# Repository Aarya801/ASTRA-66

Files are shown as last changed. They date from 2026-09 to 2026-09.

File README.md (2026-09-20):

<div align="center">

# ASTRA-66

### Parametric rocket airframe · engineering analysis · flight simulation · data-only avionics framework

**A 66 mm-class student rocket airframe designed, analysed, simulated and software-validated end to end — reproducible with one command.**









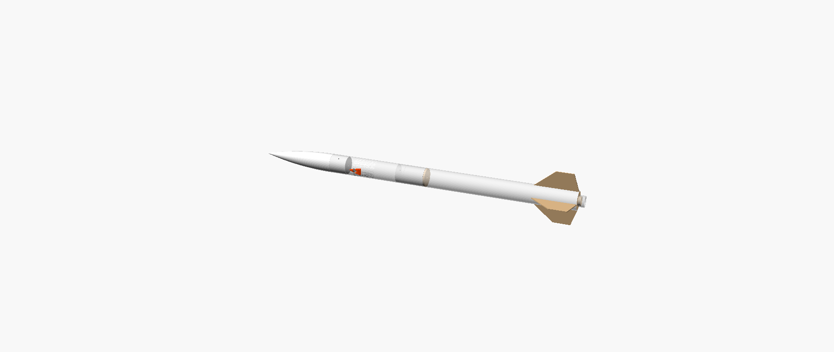
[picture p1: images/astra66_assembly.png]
ASTRA-66 assembly rendered from the OpenSCAD model


</div>

> [!IMPORTANT]
> **ASTRA-66 is an educational engineering project and is NOT FLIGHT CERTIFIED.**
> Nothing has been built or flown. No avionics hardware has been selected, bought, weighed or tested, and every
> avionics dataset is synthetic. Propulsion is an external, commercially certified component that is never designed,
> modified or specified here, and its data are placeholders. Any launch would require review and sign-off by a
> qualified rocketry mentor or institution and the range safety officer.

---

## What is ASTRA-66?

ASTRA-66 is a 66 mm-class, 1144 mm modular rocket airframe built as a **complete engineering pipeline** rather than a
drawing exercise:

- one parameter file is the single source of truth;
- the CAD is generated from it and then **measured** — volumes, interferences, assembly feasibility, printability;
- the analysis consumes those measured meshes; the simulation consumes the analysis;
- a data-only avionics software framework is exercised against synthetic sensor data through the same code path a
  flight computer would run;
- and a single command re-validates all of it, in CI, on two Python versions.

The engineering problem is **consistency and honesty**: keeping CAD, analysis, simulation and software in agreement,
and labelling every number as verified, calculated, assumed, placeholder or unknown.

| | |
|---|---|
| **Vehicle class** | 66 mm diameter · 1144 mm length · 4 fins · single parachute |
| **Modules** | Nose · payload bay · avionics bay · booster (all separable) |
| **Avionics** | Sense, log, transmit only — no actuation of any kind |
| **Propulsion** | External, commercially certified component (placeholder data only) |
| **Codebase** | 67 Python files (~10 200 lines) · 30 OpenSCAD files (~950 lines) · standard library only |
| **Artefacts** | 282 tracked files: CAD exports, drawings, plots, datasets, 37 documents |

📖 **Start here:** [Project overview](documentation/PROJECT_OVERVIEW.md) ·
[Engineering method](documentation/ENGINEERING_METHOD.md) · [What is validated](documentation/VALIDATION.md) ·
[Release readiness](documentation/RELEASE_READINESS.md)

---

## System architecture

<div align="center">
ASTRA-66 system architecture: CAD, analysis, simulation, avionics software, replay and validation, with the boundary to physical hardware validation
</div>

Everything above the red line is performed, reproducible and runs in CI. Everything below it — hardware integration
and experimental data — **has not been done**.

<details>
<summary><b>Data flow in text form</b></summary>

```
analysis/analysis.py ──► build.py ──► cad/astra66_params.scad ──► cad/build_cad.py (OpenSCAD, optional)
        │                    │                                          │
        │                    └► engineering package, BOM, drawings      └► CAD validation + CAD-derived masses
        ▼
simulation/flight_simulation.py ──► stability, sensitivity, verification, plots, reports
        ▲                                   │
simulation/motor_config.json (EXTERNAL,     └► simulation/avionics_replay.py ──► avionics/firmware
currently PLACEHOLDER)                                                           (the same pipeline a flight
                                                                                  computer would run)
```
</details>

---

## CAD

Parametric OpenSCAD model: **25 designed parts + master assembly**, driven by the generated parameter file.
Commercial items (motor envelope, retainer, rail buttons, eyebolt, electronics) appear only as **envelopes**.

<div align="center">

| Assembly | Exploded | Half-section |
|:---:|:---:|:---:|
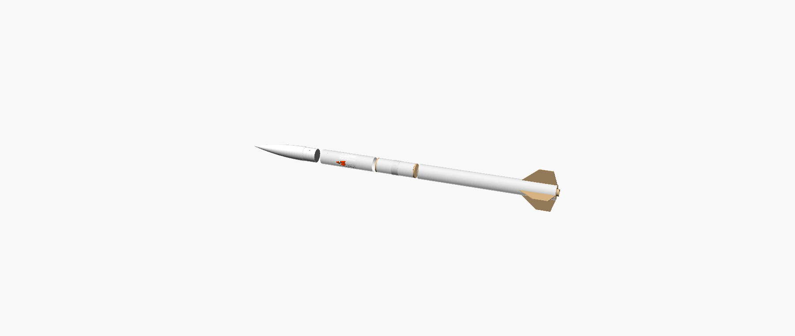
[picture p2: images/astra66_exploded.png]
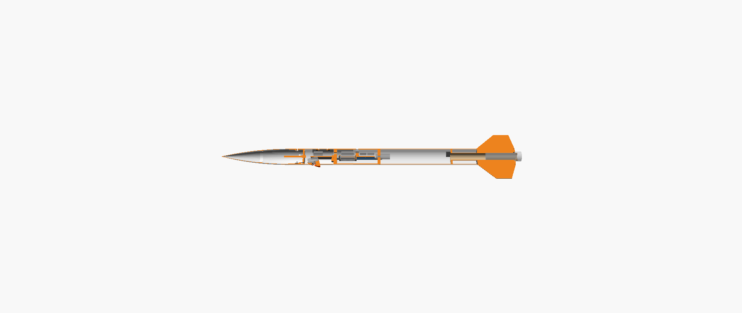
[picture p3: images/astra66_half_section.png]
|  |  |  |

</div>

| Asset | Content |
|---|---|
| `cad/exports/stl/` | 15 print-ready STLs, oriented, with documented support needs |
| `cad/exports/dxf/` | 8 DXF + 8 SVG laser/knife-cut profiles |
| [`cad/drawings/`](cad/drawings/index.html) | 31 drawing sheets generated from true mesh sections |
| [`documentation/drawings/`](documentation/drawings) | Engineering sheets A-001…A-007 |
| [`images/`](images) | Four renders produced by the CAD pipeline |

**Validation is measured on the rendered meshes**, not asserted: manifold geometry, 44 interference pairs
(0 interferences), 11 interface checks, assembly feasibility (sled removal, joint separation, fin removal with the
retainer fitted), printability and wall thickness — **147 PASS · 12 accepted WARN · 0 FAIL**
([report](documentation/CAD_VALIDATION.md)).

<details>
<summary><b>Manufacturing and bill of materials</b></summary>

- FDM-printed PETG and ASA parts (220 × 220 × 250 mm build volume is sufficient); ASA for the fin-can core near the motor.
- Laser-cut plywood bulkheads, rings and fins; purchased tube stock; metric fasteners and heat-set inserts.
- 11 printed parts need support in the documented pose; the hatch panel wall is 1.0 mm (0.25 mm nozzle recommended).
- BOM: **43 line items** (26 make, 15 buy, 2 EXTERNAL — the certified motor and igniter, never fabricated),
  17 fastener types, 10 stock materials.
- Planning cost, excluding motor, tools and shipping: **USD 232–437** (low-cost) · **292–636** (recommended).

</details>

---

## Engineering analysis

Mass budget, CG, Barrowman CP, static margin, structural loads and recovery sizing — all from the same parameters,
with structural masses derived from CAD-measured volumes.

| Result | Value | Class |
|---|---|---|
| Overall length / body OD / fin span | 1144 / 66 / 186 mm | verified from CAD |
| Liftoff mass / CG / CP | 1210.7 g / STA 696.4 mm / STA 870.3 mm | calculated |
| Static margin — liftoff / rail exit / burnout | 2.63 / 2.67 / 2.92 cal | calculated · **depends on placeholder motor data** |
| Avionics + payload subtotal | 262.7 g at STA 472.4 mm (21.7 % of liftoff mass) | calculated from assumed masses |

<details>
<summary><b>Value classes used throughout the project</b></summary>

| Class | Meaning | Examples |
|---|---|---|
| **A — verified from CAD** | Measured on the rendered meshes | lengths, volumes, clearances, interference |
| **B — calculated** | Derived from A, C and D | CG, CP, static margin, loads, descent rate |
| **C — assumption** | Engineering estimate, must be measured | densities, print fill, electronics masses, drag model |
| **D — placeholder** | Stand-in until real data exist | motor, retainer, camera, battery, switch envelopes |

"Verified" means verified against the CAD model or closed-form checks.
**No value has been verified by physical measurement or flight test.**

</details>

---

## Simulation

1-DOF vertical trajectory (RK4, ISA atmosphere, drag build-up), stability through the flight, a sensitivity study over
eight non-propulsion parameters, and **13 numerical verification checks** against closed-form solutions.

| Result — PLACEHOLDER motor, illustrative only | Value |
|---|---|
| Apogee | 328.2 m |
| Maximum speed / acceleration | 80.3 m/s · 7.4 g |
| Rail-exit speed | 11.7 m/s *(below the 15 m/s guideline — see limitations)* |
| Descent rate | 5.09 m/s |

<div align="center">
Altitude against time from the 1-DOF simulation
Static margin through the flight against the 1.5 to 3.0 calibre band
</div>

📄 [Simulation validation report](documentation/SIMULATION_VALIDATION.md) · [all plots](simulation/plots)

---

## Avionics software

A **data-only** flight-computer framework in standard-library Python, runnable without any hardware:

```
Sensor interface → schema validation → Kalman altitude/velocity estimator → flight-state classifier
                 → data logger (CSV/JSONL, CRC-16 per row) → telemetry packet v2 → ground station
```

| Capability | Detail |
|---|---|
| Sensor layer | Hardware-independent `Sensor` interface; simulated and replay sources; fault injection |
| Validation | Every value checked against the schema *before* processing; NaN, unparseable and out-of-range rejected and flagged |
| State estimation | 2-state Kalman filter (altitude, vertical velocity); barometer-only after apogee |
| Flight states | `PRELAUNCH → ASCENT → COAST → DESCENT → LANDED`, forward-only — **data labels that drive nothing** |
| Logging | Schema-conformant CSV / JSON-lines, CRC-16 per row, metadata sidecar, tolerant reader |
| Telemetry | 41-byte packet v2: sequence number, CRC-16, SIMULATED flag, per-sensor health bits |
| Ground station | Receiver with loss/duplicate/reject statistics, local server, browser dashboard (replay only) |
| Post-flight analysis | Tolerant log reader, six plot types, derived statistics, data-quality report |

<div align="center">
ASTRA-66 avionics block diagram
</div>

📄 [Avionics design](documentation/AVIONICS_DESIGN.md) · [architecture audit](documentation/AVIONICS_ARCHITECTURE.md) ·
[data format](avionics/DATA_FORMAT.md)

<details>
<summary><b>Data pipeline and synthetic datasets</b></summary>

| Dataset | Size | Mode |
|---|---|---|
| `avionics/data/example/example_flight_simulated.csv` | 4547 logged frames at 50 Hz | SYNTHETIC (legacy label `SIMULATED`) |
| `simulation/data/sample_flight.csv` | 2162 sensor-level rows with 5 scripted faults | SYNTHETIC |
| `avionics/bench_data/example_bench_record.csv` | 501-row column template for future bench records | SYNTHETIC — **not a measurement** |

Data-source modes are enforced in code: `SYNTHETIC`, `BENCH` and `FLIGHT`, where **`FLIGHT` is disabled** because no
flight record exists. Plots, reports and telemetry all carry the mode.

</details>

---

## Validation



```bash
python run_validation.py
```

| # | Step | Result |
|---|---|---|
| 1 | Engineering package build | ✅ PASS |
| 2 | CAD integration — 147 PASS · 12 accepted WARN · 0 FAIL | ✅ PASS |
| 3 | Flight simulation — 13/13 verification checks | ✅ PASS |
| 4 | Avionics sensor replay | ✅ PASS |
| 5 | CAD fit and mass properties — 11 PASS · 4 WARN · 8 UNVERIFIED · 0 FAIL | ✅ PASS |
| 6 | Project regression tests — 74 tests | ✅ PASS |
| 7 | Avionics software tests — 81 tests | ✅ PASS |
| | **Overall — 155 tests, 0 failures** | ✅ **PASS** |

The same command runs in GitHub Actions on **Python 3.12 and 3.14** for every push and pull request, and
`MANIFEST.sha256` checksums every tracked file.

📄 [What is and is not validated](documentation/VALIDATION.md) · [test plan](documentation/TEST_PLAN.md)

---

## Repository structure

```
ASTRA-66/
├── analysis/          analysis.py (single source of truth) + generated results
├── cad/               OpenSCAD sources, exports (STL/DXF), drawings, build pipeline
├── simulation/        flight simulation, sensor replay, datasets, results, plots
├── avionics/          firmware, ground station, analysis tool, schema, data, integration checks, tests
├── documentation/     engineering package, validation reports, portfolio documents, diagrams
├── bom/               bom.csv, fasteners.csv, materials.csv
├── tests/             project regression tests
├── images/            CAD renders
├── hosting/ + dist/   standalone engineering-package page
├── run_validation.py  the one command
└── MANIFEST.sha256    checksum of every tracked file
```

---

## Technology and tool stack

| Layer | Tool | Notes |
|---|---|---|
| Language | Python 3.12 / 3.14 | **Standard library only** — no third-party packages anywhere |
| CAD | OpenSCAD 2021.01 (CGAL) | Optional: needed only to re-render; exports are committed |
| Mesh analysis | Own pure-Python tools | STL read/write, volume and centroid, manifold checks, plane slicing, overhang |
| Numerics | Own implementations | RK4 integrator, ISA atmosphere, Barrowman CP, 2-state Kalman filter |
| Data formats | CSV / JSON / JSON-lines | Deterministic, schema-driven, CRC-16 per row |
| Drawings and plots | Own SVG generators | No plotting library; drawings built from true mesh sections |
| Web | Vanilla HTML + JS, `http.server` | Engineering package page; ground-station dashboard |
| Tests | `unittest` | 155 tests, hardware-free |
| CI | GitHub Actions | Matrix over two Python versions, artefact upload |
| Integrity | SHA-256 manifest | Every tracked file checksummed |

---

## Engineering workflow and milestones

The workflow the project follows (details: [engineering method](documentation/ENGINEERING_METHOD.md)):

```
requirements → CAD → analysis → simulation → validation → hardware integration → testing
     ✅          ✅       ✅          ✅           ✅              ⬜ not started       ⬜ not started
```

Milestones as recorded in this repository's git history:

| Commit | Date | Milestone |
|---|---|---|
| [`e503ef6`](https://github.com/Aarya801/ASTRA-66/commit/e503ef6) | 2026-09-19 | Initial engineering package: parameters, CAD rev B with validation, analysis, simulation, documentation, tests |
| [`4c8d193`](https://github.com/Aarya801/ASTRA-66/commit/4c8d193) | 2026-09-19 | CI validation badge |
| [`bc430a3`](https://github.com/Aarya801/ASTRA-66/commit/bc430a3) | 2026-09-20 | Avionics and flight-data framework: firmware, ground station, replay, integration checks, 7-step pipeline |

---

## Current status

| Area | Status |
|---|---|
| Software behaviour | ✅ Verified by 155 automated tests on synthetic data |
| CAD model | ✅ Validated against the rendered meshes (0 FAIL, 0 interferences) |
| Simulation code | ✅ Verified against closed-form solutions (13/13) |
| Trajectory numbers | ⚠️ **Illustrative** — placeholder propulsion data |
| Avionics hardware | ⛔ **Nothing selected, built, weighed or tested** |
| Physical fit and masses | ⛔ **Unverified** — 8 items need measurement |
| Flight behaviour, recovery, radio range | ⛔ **Never tested** |

📄 [Hardware-integration status](documentation/HARDWARE_INTEGRATION_STATUS.md) ·
[hardware integration](documentation/HARDWARE_INTEGRATION.md) · [roadmap](documentation/ROADMAP.md)

---

## ⚠️ Safety status — NOT FLIGHT CERTIFIED

> [!WARNING]
> **ASTRA-66 is NOT FLIGHT CERTIFIED and has never flown.**

- **No propulsion work of any kind.** No motors, propellant, igniters, pyrotechnics or energetic devices are designed,
  modified, specified or described. The motor is an external, commercially certified product, selected and handled by
  a certified person; recovery uses that motor's own ejection, prepared by a mentor.
- **No actuation.** The avionics sense, log and transmit. There is no output that could drive an igniter or a
  deployment device, and a test fails the build if an actuation-style identifier or a hardware-I/O import appears.
- **No autonomous flight control.**
- **Radio only where legal:** any telemetry radio must use a band and power level legal where it is operated, with
  range frequency coordination.
- **Nothing is presented as measured.** Synthetic data and placeholders are labelled as such; the `FLIGHT` data mode
  is disabled in software until a genuine, mentor-reviewed flight record exists.

---

## Limitations and future experimental work

<details open>
<summary><b>Known limitations carried into this release</b></summary>

1. Propulsion data are placeholders: every trajectory value, and any margin including the motor, is provisional.
2. Rail-exit speed 11.7 m/s on the 1.0 m planning rail is below the 15 m/s guideline (placeholder input).
3. About 100 g extra in the payload bay pushes the static margin above 3.0 calibres (over-stable).
4. Four open CAD integration warnings: incomplete electronics envelopes; IMU placeholder 20.5 mm off the roll axis;
   steel rods beside the radio envelope; 0.40 mm sled-removal margin.
5. Twelve accepted CAD warnings: 11 printed parts need support; the hatch wall is 1.0 mm.
6. Barometric altitude is biased above an elevated pad (≈1.1 % at 500 m); the planning site is at 0 m.
7. Thresholds, filter tuning and sensor requirements are assumptions checked only on synthetic data.
8. Uncalibrated drag model; 1-DOF flight model (no wind, weathercocking or dynamic stability).
9. Structures: hand calculations with conservative allowables; no FEA, no coupon tests.

</details>

**Future experimental work**, in order and none of it started: mentor-approved component selection → measure and weigh
the parts → update the CAD envelopes and mass budget → bench tests B-01…B-14 → record real sensor data and compare it
with the simulation → certified motor data → supervised testing only with a mentor and range approval.

📄 [Roadmap](documentation/ROADMAP.md) · [bench-test plan](documentation/AVIONICS_BENCH_TEST_PLAN.md) ·
[selection checklist](documentation/HARDWARE_SELECTION_CHECKLIST.md)

---

## Setup and reproducibility

**Requirements:** Python 3.12 or newer. Nothing to install — standard library only.

```bash
git clone https://github.com/Aarya801/ASTRA-66.git
cd ASTRA-66
python run_validation.py
```

Expected ending: `OVERALL: PASS` (exit code 0) with the seven steps above.

<details>
<summary><b>Other commands</b></summary>

```bash
python -m unittest discover -s tests                 # project regression tests (74)
python -m unittest discover -s avionics/tests -t .   # avionics software tests (81)
python simulation/flight_simulation.py               # simulation only
python simulation/avionics_replay.py                 # replay the synthetic sensor dataset
python -m avionics.firmware.simulate_flight          # simulated flight through the avionics software
python avionics/analysis/flight_data_analysis.py avionics/data/example/example_flight_simulated.csv
python avionics/ground_station/server.py --sensors simulation/data/sample_flight.csv
python avionics/integration/cad_mass_integration.py --check
python build.py                                      # engineering package only
python hosting/make_standalone.py                    # standalone package page → dist/index.html
```

Optional CAD re-render (OpenSCAD 2021.01 from openscad.org, not bundled):

```bash
python run_validation.py --with-cad --openscad "C:/path/to/openscad.com"
```

</details>

Every committed result regenerates from the sources, and `MANIFEST.sha256` checksums every tracked file. Generated
reports carry their run date, so only those date fields change between runs.

📄 [Full reproducibility guide](documentation/REPRODUCIBILITY.md)

---

## Documentation map

| Document | Purpose |
|---|---|
| [Project overview](documentation/PROJECT_OVERVIEW.md) | What the project is, architecture, workflows, limitations |
| [Engineering method](documentation/ENGINEERING_METHOD.md) | How the work is done and what evidence each stage produces |
| [Validation](documentation/VALIDATION.md) | What is validated, how, and what is not |
| [Test plan](documentation/TEST_PLAN.md) | Software, CAD, simulation, bench and future physical tests |
| [Hardware integration](documentation/HARDWARE_INTEGRATION.md) | Interfaces vs synthetic data vs unselected hardware |
| [Hardware-integration status](documentation/HARDWARE_INTEGRATION_STATUS.md) | Item-by-item audit of the whole repository |
| [Selection checklist](documentation/HARDWARE_SELECTION_CHECKLIST.md) · [mass procedure](documentation/MASS_MEASUREMENT_PROCEDURE.md) | How to choose and measure real parts |
| [Reproducibility](documentation/REPRODUCIBILITY.md) · [roadmap](documentation/ROADMAP.md) · [release readiness](documentation/RELEASE_READINESS.md) | Running it, what comes next, freeze record |
| [Visual index](documentation/images/README.md) | Every render, drawing, plot and diagram |

---

## License

MIT License ([`LICENSE`](LICENSE)); the "AS IS" warranty disclaimer applies. The project safety notice in `LICENSE`
and the NOT FLIGHT CERTIFIED statement in this README must be kept with any copy.

<div align="center">

**ASTRA-66 — educational engineering project · NOT FLIGHT CERTIFIED · propulsion is an external, commercially certified component**

</div>

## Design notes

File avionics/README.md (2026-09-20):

# avionics/

The electronics handle sensing, logging and telemetry only. **No channel can drive an igniter, charge or any energetic device.**
Recovery uses the certified motor's own ejection, prepared by a mentor.

> **Phase 4 status: software architecture and simulation only. The avionics are NOT flight certified.** No avionics
> component has been selected, built or tested; every sensor is **COMPONENT TO BE SELECTED**. All data in this folder
> are **SIMULATED** and labelled as such. Real-time and flight capability have not been demonstrated.

## Contents

| Path | Kind | Content |
|---|---|---|
| `electronics.csv` | generated by `build.py` | Module list: function, example class (verify datasheets), bus, location, cost, build level |
| `diagrams/arch.svg` | generated | System architecture: modules, interfaces I-00…I-08, load paths |
| `diagrams/elec.svg` | generated | Avionics block diagram (power, I²C, SPI, UART, GPIO) |
| `diagrams/fsm.svg` | generated | Flight-phase detection state machine (logging only) |
| `architecture/system_architecture.md` | Phase 4 | Layers, design principles, block diagram (`architecture/avionics_block_diagram.svg`) |
| `architecture/data_flow.md` | Phase 4 | Data path, rates, freshness rule, error handling, data-source labels |
| `architecture/interface_spec.md` | Phase 4 | Every sensor, software and physical interface |
| `firmware/` | Phase 4 | Hardware-independent flight-computer software: sensor interfaces, flight state, logging, telemetry |
| `data/schema/flight_data_schema.json` | Phase 4 | Flight-data schema (fields, units, rates, plausibility limits) |
| `data/example/` | Phase 4 | SIMULATED example flight log, metadata and telemetry capture |
| `ground_station/` | Phase 4 | Receiver, local server and browser dashboard (prototype) |
| `analysis/flight_data_analysis.py` | Phase 4 | Post-flight analysis: plots and derived statistics |
| `tests/` | Phase 4 | Hardware-free tests of all of the above |
| `HARDWARE_MAPPING.md` | Phase 5 | Logical component → generic hardware class; required / optional; validation and approval needs |
| `DATA_FORMAT.md` | Phase 5 | Every file and packet format: units, decimals, ranges, validity flags |
| `integration/` | Phase 5 | CAD fit and avionics mass-properties check; report `documentation/CAD_AVIONICS_INTEGRATION.md` |
| `firmware/data_source.py` | Phase 6 | Data-source modes SYNTHETIC / BENCH / FLIGHT (FLIGHT disabled: no flight data exist) |
| `bench_data/` | Phase 6 | Where bench recordings go; column template with synthetic values |

Design document: `documentation/AVIONICS_DESIGN.md`. Phase 5 audit and block diagram:
`documentation/AVIONICS_ARCHITECTURE.md`; status: `documentation/PHASE_5_STATUS.md`. Phase 6 readiness review,
selection checklist, bench-test plan and mass procedure: `documentation/HARDWARE_INTEGRATION_STATUS.md`,
`documentation/HARDWARE_SELECTION_CHECKLIST.md`, `documentation/AVIONICS_BENCH_TEST_PLAN.md`,
`documentation/MASS_MEASUREMENT_PROCEDURE.md`.

Every number here is either verified by software test on synthetic data, an engineering assumption, or unverified
until measured; no component is selected and nothing has been weighed
(`documentation/HARDWARE_INTEGRATION_STATUS.md`).

## Quick start (no hardware needed)

```bash
python -m avionics.firmware.simulate_flight
python avionics/analysis/flight_data_analysis.py avionics/data/example/example_flight_simulated.csv
python avionics/ground_station/server.py --simulate --speed 2
python -m unittest discover -s avionics/tests -t .
```

The third command serves the dashboard at http://127.0.0.1:8766/ (localhost only). `python run_validation.py` runs the
avionics tests together with the rest of the project.

## Mechanical provisions (CAD rev B)
- **Sled** (`cad/parts/AV-306_electronics_sled.scad`):
  - 10 M2.5 insert bosses on a 25 mm pitch;
  - switch tower with an M2.5 insert (height `SW_TOWER_H`, USER);
  - 2 M3 inserts for the battery cage;
  - zip-tie slots.
- **Battery cage** `AV-308`: open bottom, strap-retained. The cell must be no wider than 28.8 mm to clear the rod sleeves.
- **GPS / sensor tray** `PL-202`: in the payload bay under the service hatch; 6 M2.5 bosses.
- **Camera cradle** `PL-203`, with the lens cowl `PL-204` at 270°, tilted 15° aft.
- **Placeholder envelopes:** module, battery, GPS, camera and switch envelopes are in `cad/parts/COTS_envelopes.scad`. Replace them with your measured parts and re-run the CAD pipeline. Interference and clearance are re-checked automatically.

Phase 4 did not change any CAD file. How the avionics must fit these provisions is set out in
`architecture/interface_spec.md` §3.

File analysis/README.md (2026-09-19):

# analysis/

| Path | Kind | Content |
|---|---|---|
| `analysis.py` | **source** | Every design parameter (with provenance tag), stations, mass budget, Barrowman CP, static margin, fin trade study, recovery, structural loads, flutter screening, vibration estimate |
| `results/analysis.json` | generated | Summary results (masses, CG, CP, margins, loads, recovery, stations, motor-data status) |
| `results/mass_budget.csv` | generated | Item-level mass budget; CAD-derived items are noted `CAD:` |
| `results/parameters.csv` | generated | All parameters with value, unit, provenance and note |

`python analysis/analysis.py` prints a quick summary. `python build.py` (at the project root) regenerates the results and
the whole package.

Inputs that `analysis.py` reads:
- `simulation/motor_config.json`: external motor / retainer data (PLACEHOLDER until verified);
- `cad/exports/cad_mass_properties.json`: masses and CGs measured from the CAD by `cad/build_cad.py`.

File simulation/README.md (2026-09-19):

# simulation/

A transparent, standard-library-only flight-simulation and engineering-validation pipeline. It uses the CAD-derived
mass properties and geometry as its source of truth.

**Draft student design, not flight certified.** Propulsion is an external, commercially certified component. This
folder only *reads* motor data (masses and a thrust-time table). It never designs, modifies or optimises a motor.

## Reproduce everything: one command

Requirements: Python 3.12+ (tested 3.12.10 and 3.14.6); no third-party packages; no network.

```bash
git clone <repository> ASTRA-66
cd ASTRA-66
python run_validation.py
```

Expected console result (numbers are for the committed inputs):
```
  wrote documentation/ENGINEERING_STATUS.md
ASTRA-66 validation pipeline
  [PASS] Engineering package build (build.py)
  [PASS] CAD integration (committed validation is current)
  [PASS] Flight simulation, stability, sensitivity, reports
         apogee 328.2 m (PLACEHOLDER TEST INPUT)  v_max 80.3 m/s  a_max 7.4 g  rail exit 11.7 m/s  SM rail 2.67 cal  descent 5.09 m/s
         verification 13/13 passed; ...
  [PASS] Regression tests
OVERALL: PASS
```
The exit code is 0 on PASS and 1 on any failure.

Optional full CAD regeneration (external OpenSCAD 2021.01, about 3 minutes):
`python run_validation.py --with-cad --openscad "C:/path/to/openscad.com"`.

### Files the command (re)generates

| File | Content |
|---|---|
| `simulation/results/flight_summary.json` | inputs, results, events, envelope checks, verification, placeholder-dependence map |
| `simulation/results/stability_report.md` | CP (CAD cross-check), CG, static margin vs time/mass/payload/CG, requirement check |
| `simulation/results/sensitivity_report.md` | one-at-a-time sensitivity tables and ranking |
| `simulation/results/sensitivity_table.csv` | all sensitivity runs |
| `simulation/results/trajectory_baseline.csv` | baseline time history (units in the header) |
| `simulation/results/pipeline_status.json` | step-by-step PASS/FAIL of the last run |
| `simulation/plots/*.svg` | 16 labelled plots (trajectory, stability, drag, sensitivity) |
| `documentation/SIMULATION_VALIDATION.md` | full simulation validation report |
| `documentation/ENGINEERING_STATUS.md` | project-wide engineering status |
| `documentation/ASTRA-66_Engineering_Package.html`, `analysis/results/`, `bom/`, `avionics/` | from `build.py` |

**Determinism:** the same inputs give the same numbers. The simulation is a fixed-step RK4 with no random elements,
checked by `tests/test_simulation.py::Reproducibility`. Only the run-date fields in reports change between runs.

## Inputs (the only files to edit)

| File | Holds | Status |
|---|---|---|
| `simulation/motor_config.json` | motor / retainer / MMT data and `thrust_curve_file` | **PLACEHOLDER** |
| `simulation/motors/PLACEHOLDER_TEST_INPUT.eng` | synthetic thrust signal (**not a real motor**) | PLACEHOLDER |
| `simulation/sim_config.json` | launch site, rail length override, drag assumptions, time steps | planning defaults / ASSUMPTION |
| `analysis/analysis.py` | airframe parameters (the CAD reads them too) | see parameter provenance tags |

All inputs are validated. The pipeline stops with an explanatory error in any of these cases:
- a value is out of range;
- `MANUFACTURER_DATA` is claimed without source, verifier and date;
- the placeholder curve is still referenced;
- the `.eng` masses, length or diameter disagree with the config or the MMT bore.

## Modules

| Module | Purpose |
|---|---|
| `flight_simulation.py` | 1-DOF vertical RK4 simulation and pipeline entry point |
| `stability.py` | Barrowman CP re-implemented independently; static margin; requirements REQ-STAB-1..3 |
| `mass_properties.py` | vehicle mass/CG from `analysis/analysis.py` (21 CAD-derived items); data classes A–D |
| `atmosphere.py` | ISO 2533 standard atmosphere |
| `aerodynamics.py` | drag build-up (ASSUMPTION model) |
| `motor.py` | RASP `.eng` reader, impulse-proportional mass, cross-checks |
| `config.py` | `sim_config.json` loader and validator |
| `sensitivity.py` | one-at-a-time non-propulsion sensitivity study |
| `verification.py` | 13 numerical verification checks (closed-form solutions and cross-checks) |
| `plotting.py`, `report.py` | dependency-free SVG plots; JSON/Markdown/CSV writers |

## What depends on placeholder propulsion data

While `motor_config.json` is `PLACEHOLDER`, **every trajectory, acceleration, altitude, apogee, rail-exit speed,
descent-rate and with-motor static-margin value is illustrative only and not representative of any real motor.**

Two things are also affected, less obviously:
- The "no-motor" margin (3.23 cal) excludes the motor, but still contains the placeholder retainer mass and the MMT sized from placeholder data.
- Burn-phase base drag uses the placeholder MMT bore.

The CP and the coast drag model are independent of propulsion data. `flight_summary.json` carries the full map under `placeholder_dependency`.

## Replacing the placeholder with a certified motor

The mentor selects a legally obtainable certified motor. Then:
1. Put the motor's **published** RASP `.eng` file (from the manufacturer or the certifying organisation) in `simulation/motors/`.
2. In `motor_config.json`:
   - set `thrust_curve_file`;
   - copy the published masses, length, diameter and retainer/MMT dimensions;
   - fill in `designation`, `manufacturer`, `certification`, `data_source`, `retainer.model`, `retainer.data_source`, `verification.verified_by` and `verification.date`;
   - set `"status": "MANUFACTURER_DATA"`.
3. Run `python run_validation.py --with-cad --openscad <path>`. This re-sizes the MMT, retainer envelope, lock ring and fin tabs, then re-validates the CAD and re-runs the simulation.
4. Review the regenerated reports with the mentor. Pay particular attention to:
   - rail-exit speed on the range's rail (15 m/s guideline);
   - static margin 1.5–3.0 cal;
   - coast time against the motor's delay options.

## OpenRocket cross-check
Build the OpenRocket model from `simulation/openrocket_inputs.csv`, using weighed masses. Compare its no-motor CG and CP
with `analysis/results/analysis.json` (±10 / ±15 mm). Then compare its drag and apogee with this pipeline for the same
certified motor.

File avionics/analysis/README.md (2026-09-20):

# avionics/analysis/

Post-flight analysis of a flight-data log that follows `avionics/data/schema/flight_data_schema.json`.

> All datasets in this repository are synthetic; no flight or bench data exist. ASTRA-66 is NOT flight certified.

```bash
python avionics/analysis/flight_data_analysis.py avionics/data/example/example_flight_simulated.csv
python avionics/analysis/flight_data_analysis.py LOG.csv --out some/folder
```

## Outputs (default folder `results/<log name>/`)

| Output | Content |
|---|---|
| `altitude_vs_time.svg` | Barometric altitude above the pad, apogee marked |
| `velocity_vs_time.svg` | Vertical velocity derived from barometric altitude, and the logged onboard estimate |
| `acceleration_vs_time.svg` | Axial specific force and acceleration magnitude |
| `temperature_vs_time.svg` | Bay temperature |
| `battery_voltage_vs_time.svg` | Battery voltage |
| `gps_track.svg` | Ground track relative to the first fix (only if the log has GNSS fixes) |
| `flight_summary.json`, `flight_report.md` | Data quality, derived statistics, event times |

The committed example output is in `results/example_flight_simulated/`. It is **SIMULATED DATA**, derived from the
PLACEHOLDER propulsion input, and every plot and report says so.

## Derived statistics (all CALCULATED from the log)

| Statistic | Method |
|---|---|
| Apogee | maximum of the 0.3 s moving average of barometric altitude |
| Max vertical velocity | derivative of smoothed altitude (smoothing blunts sharp peaks by a few m/s); onboard estimate reported alongside |
| Max axial specific force / acceleration magnitude | maximum accelerometer reading |
| Descent rate | median derived descent speed from 2 s after apogee to 1 s before landing |
| Event times | state-label time minus the classifier's confirmation time; apogee = time of maximum smoothed altitude |
| Burn, time to apogee, flight and descent durations | differences of event times |
| Temperature, battery | start, minimum, maximum, mean, end; battery drop = start − minimum |
| GNSS | fixes, first and last fix, last-fix and maximum distance from the first fix, track length |
| Data quality | rows read and usable, dropped rows by reason, rejected values by field, timestamp gaps, CRC check |

If the log has no `flight_state` column values, states are reconstructed offline with the same classifier.

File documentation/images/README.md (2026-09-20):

# ASTRA-66 — Visual index

Every image here is **generated by the project's own pipeline** from the CAD model, the analysis or the simulation.
Nothing is a photograph, a rendering made by hand, or a measurement: no hardware exists and nothing has flown.
Trajectory plots use the **placeholder** motor data, so they show software behaviour and sensitivities, not
predictions. ASTRA-66 is NOT FLIGHT CERTIFIED.

Files are referenced where the pipeline writes them, so nothing is duplicated in the repository.

## System architecture

| Image | What it shows |
|---|---|
| [`astra66_system_architecture.svg`](astra66_system_architecture.svg) | CAD → analysis → simulation → avionics software → replay → validation, with the explicit boundary to the physical hardware validation that has **not** been performed |
| [`../../avionics/architecture/avionics_block_diagram.svg`](../../avionics/architecture/avionics_block_diagram.svg) | Avionics block diagram: sensors, flight computer, logging, telemetry, ground station, and the "no actuation outputs" boundary |

## CAD (rendered from the OpenSCAD model)

| Image | What it shows |
|---|---|
| [`../../images/astra66_assembly.png`](../../images/astra66_assembly.png) | Assembled airframe, commercial envelopes shown transparent |
| [`../../images/astra66_exploded.png`](../../images/astra66_exploded.png) | Exploded assembly: nose, payload bay, avionics bay, booster |
| [`../../images/astra66_half_section.png`](../../images/astra66_half_section.png) | Half-section: internal structure, sled, bulkheads, motor tube |
| [`../../images/astra66_vertical.png`](../../images/astra66_vertical.png) | Vertical view of the complete vehicle |

## Engineering drawings (generated from true mesh sections)

| Sheet | Content |
|---|---|
| [`../../cad/drawings/CAD-A01.svg`](../../cad/drawings/CAD-A01.svg) | Full assembly section, 1:1 |
| [`../../cad/drawings/index.html`](../../cad/drawings/index.html) | Index of all 31 CAD sheets (one per part plus assembly sections) |
| [`../drawings/ga.svg`](../drawings/ga.svg) | Engineering sheet A-001: general arrangement |
| [`../drawings/ex.svg`](../drawings/ex.svg) | Engineering sheet A-002: exploded view |
| [`../drawings/av.svg`](../drawings/av.svg) | Engineering sheet: avionics bay |

## Simulation (placeholder propulsion — illustrative only)

| Plot | What it shows |
|---|---|
| [`../../simulation/plots/altitude_vs_time.svg`](../../simulation/plots/altitude_vs_time.svg) | Altitude against time |
| [`../../simulation/plots/velocity_vs_time.svg`](../../simulation/plots/velocity_vs_time.svg) | Vertical velocity against time |
| [`../../simulation/plots/static_margin_vs_time.svg`](../../simulation/plots/static_margin_vs_time.svg) | Static margin through the flight against the 1.5–3.0 calibre band |
| [`../../simulation/plots/tornado_apogee.svg`](../../simulation/plots/tornado_apogee.svg) | Sensitivity of apogee to the non-propulsion parameters |
| [`../../simulation/plots/drag_coefficient_vs_mach.svg`](../../simulation/plots/drag_coefficient_vs_mach.svg) | Drag build-up against Mach number (assumption) |

## Avionics data (synthetic)

| Plot | What it shows |
|---|---|
| [`../../avionics/analysis/results/example_flight_simulated/altitude_vs_time.svg`](../../avionics/analysis/results/example_flight_simulated/altitude_vs_time.svg) | Altitude recovered by the post-flight tool from a synthetic flight log |
| [`../../avionics/analysis/results/example_flight_simulated/velocity_vs_time.svg`](../../avionics/analysis/results/example_flight_simulated/velocity_vs_time.svg) | Velocity derived from barometric altitude versus the onboard estimator |
| [`../../avionics/analysis/results/example_flight_simulated/gps_track.svg`](../../avionics/analysis/results/example_flight_simulated/gps_track.svg) | Ground track from synthetic GNSS fixes (fictitious origin) |

## Validation evidence

| Artefact | Content |
|---|---|
| [`../CAD_VALIDATION.md`](../CAD_VALIDATION.md) | Full CAD validation report: 147 PASS · 12 accepted WARN · 0 FAIL |
| [`../SIMULATION_VALIDATION.md`](../SIMULATION_VALIDATION.md) | Simulation validation: 13/13 numerical verification checks |
| [`../ENGINEERING_STATUS.md`](../ENGINEERING_STATUS.md) | Generated status: what is verified by software, what needs a bench, what needs qualified review |
| [`../CAD_AVIONICS_INTEGRATION.md`](../CAD_AVIONICS_INTEGRATION.md) | CAD ↔ avionics fit and mass properties: 11 PASS · 4 WARN · 8 UNVERIFIED · 0 FAIL |

Regenerate everything with `python run_validation.py` (add `--with-cad --openscad <path>` for the CAD renders).

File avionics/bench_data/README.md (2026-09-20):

# avionics/bench_data/

Where **bench recordings** from real avionics hardware are kept, once such hardware exists.

> **There is no real bench data in this repository yet.** `example_bench_record.csv` is a **column template whose
> values are synthetic** (generated by the simulated sensors), so its `data_source` column says `SYNTHETIC`. Nothing in
> this folder is a measurement, flight data, or evidence that any component works. ASTRA-66 is NOT flight certified.

## Format

A bench record uses the same sensor-level CSV format as the replay input (`avionics/DATA_FORMAT.md` §3), so the same
processing pipeline reads synthetic, bench and (later) flight data without any change to the processing code:

```bash
python simulation/avionics_replay.py avionics/bench_data/<your-record>.csv --out simulation/results/<name>
```

Columns: `timestamp`, `data_source`, then the sensor fields. Rules that matter for a real recording:

- **`data_source` must be `BENCH` in every row** of a genuine bench recording (`SYNTHETIC` only for generated values,
  `FLIGHT` is disabled in software until a real flight record exists: `avionics/firmware/data_source.py`).
- One row per tick on a uniform grid; empty cell = no sample from that sensor at that tick.
- Record what the sensor produced, including implausible values: validation is the flight computer's job and rejecting
  bad data is one of the things the bench test checks.
- Do not edit values by hand. If a value is wrong, note it in the meta file instead.

## Meta file

Every recording needs a sidecar `<name>.meta.json` next to it. Fill in only what was actually done:

```json
{
  "title": "ASTRA-66 bench record",
  "data_source": "BENCH",
  "test_id": "B-03 (see documentation/AVIONICS_BENCH_TEST_PLAN.md)",
  "date": "YYYY-MM-DD",
  "operator": "name",
  "mentor_present": false,
  "hardware": {
    "flight_computer": "board and revision",
    "imu": "part number, breakout revision",
    "barometer": "part number",
    "gnss": "module and antenna",
    "temperature": "part number or 'barometer internal'",
    "battery": "cell type and capacity",
    "storage": "card type",
    "radio": "module, band and power setting (must be legal where operated)"
  },
  "firmware": {"commit": "git commit", "log_rate_hz": 100, "notes": ""},
  "setup": "bench layout, orientation, what was moved or heated, reference instruments used",
  "reference_instruments": ["multimeter make/model", "reference barometer", "scale"],
  "known_issues": ["what went wrong, loose connector, etc."],
  "values_are_measurements": true
}
```

Set `"values_are_measurements": false` for any file whose values were generated, as in the example template.

## Regenerating the example template

```bash
python simulation/avionics_replay.py --make-bench-example
```

It writes 10 s of synthetic pad data (50 Hz) with no injected faults, purely to show the column layout.

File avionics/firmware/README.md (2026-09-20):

# avionics/firmware/

Hardware-independent reference implementation of the flight-computer software, in standard-library Python. It runs
today against **SIMULATED** sensors; the same structure is meant to be ported to the selected microcontroller
(COMPONENT TO BE SELECTED) later. It is not flight software and is not flight certified.

| Module | Layer | Content |
|---|---|---|
| `sensor_interfaces/base.py` | Sensor layer | `Sensor` interface, `SensorSample`, fixed-rate scheduling, `HardwareSensorPlaceholder` (refuses to read) |
| `sensor_interfaces/catalog.py` | Sensor layer | Requirement table for every sensor (all COMPONENT TO BE SELECTED) |
| `sensor_interfaces/simulated.py` | Sensor layer | Truth profiles (replay of the existing trajectory, synthetic test profile), simulated IMU / barometer / GNSS / temperature / battery / breakwire, seeded noise, fault injection |
| `flight_state/estimator.py` | Processing | Pad reference pressure, ISA pressure → altitude, 2-state Kalman filter (barometer-only after apogee) |
| `flight_state/classifier.py` | Processing | PRELAUNCH → ASCENT → COAST → DESCENT → LANDED, forward only, with the transition assumptions in its docstring. Data label only |
| `logging/schema.py` | Logger | Loads the schema; validates, formats and parses values |
| `logging/timebase.py` | Logger | Counter unwrapping (32-bit µs wrap), timestamp monitor (duplicate, backwards, gap) |
| `logging/logger.py` | Logger | `DataLogger`, CSV and JSON-lines sinks with CRC-16, memory sink, metadata sidecar |
| `logging/reader.py` | Logger | Tolerant log reader used by the analysis |
| `telemetry/packet.py` | Telemetry | 41-byte packet v2 (v1 still decoded): encode / decode, sensor-health bits, saturation, missing-value sentinels, CRC-16 |
| `telemetry/link.py` | Telemetry | `SimulatedTelemetryLink` (loss, bit errors) and `HardwareTelemetryLink` (interface only; no radio selected) |
| `crc.py` | shared | CRC-16/CCITT-FALSE |
| `flight_computer.py` | all | Main loop: sensors → processing → logger + telemetry. No outputs other than log and link |
| `simulate_flight.py` | tool | Runs a simulated flight and writes a log, metadata and a telemetry capture |

## Run

```bash
python -m avionics.firmware.simulate_flight                       # regenerates avionics/data/example/
python -m avionics.firmware.simulate_flight --out-dir out --seed 3 --loss 0.1
```

Run it as a module (`-m`) from the repository root. The package `avionics.firmware.logging` must always be imported
through its full name; putting `avionics/firmware` itself on `sys.path` would shadow Python's standard `logging`.

## Porting notes (future hardware work)

- Keep the layer boundaries: one driver per selected sensor behind `Sensor`; an SD-card sink behind `LogSink`; a radio
  driver behind `HardwareTelemetryLink`.
- Keep integer microsecond timestamps from a free-running timer and unwrap them (`logging/timebase.py`).
- Re-derive the classifier thresholds and sensor ranges with the certified motor's published data, then re-run the
  tests with a trajectory built from that data.
- Measure loop timing, SD write latency and power on the bench before any flight consideration.

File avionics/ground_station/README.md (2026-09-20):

# avionics/ground_station/

Ground-station **prototype**: decodes telemetry packets, keeps link statistics and shows the data in a browser
dashboard. It has only ever been run on **SIMULATED TELEMETRY**. It is a development tool, **not validated for real-time
flight use**, and like the rest of the avionics it is **not flight certified**.

| File | Content |
|---|---|
| `receiver.py` | `GroundStationReceiver`: decode, reject bad packets, count missing / duplicate sequence numbers, CSV log; capture-file reader |
| `server.py` | Local HTTP server (standard library): replays a capture, runs a fresh simulated flight, or replays a sensor-level dataset through the flight-computer software; `GET /api/telemetry?after=N` |
| `dashboard/index.html` | Self-contained dashboard (no external files): flight state, sensor health (IMU / baro / GNSS / temperature / battery), GPS status, battery status, packet count and loss, latest telemetry time, altitude, vertical velocity, acceleration, temperature, GPS position and track, battery voltage; light and dark themes |

## Run

```bash
python avionics/ground_station/server.py                      # replay the committed SIMULATED capture
python avionics/ground_station/server.py --simulate --speed 2 --loop
python avionics/ground_station/server.py --sensors simulation/data/sample_flight.csv   # sensor-level replay (Phase 5)
```

Battery status uses 1S planning thresholds (LOW below 3.6 V, CRITICAL below 3.4 V); these are assumptions, not values
from a datasheet. Sensor health comes from telemetry packet v2 (a v1 capture shows "?").

Open http://127.0.0.1:8766/ . The server binds to localhost only. The banner always states the data source; with the
current software it is always "SIMULATED TELEMETRY: not flight data".

## Limits

- REAL HARDWARE TELEMETRY is not implemented: no radio has been selected (COMPONENT TO BE SELECTED). The hardware link
  class refuses to start without a radio driver.
- The server replays packets at their recorded times. Latency, throughput and robustness with a real radio and a real
  serial connection have not been measured.
- "Missing sequence numbers" counts packets dropped in the air and packets rejected as corrupted.

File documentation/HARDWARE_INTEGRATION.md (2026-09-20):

# ASTRA-66 — Hardware integration: what is software, what is synthetic, what is missing

> **No avionics hardware has been selected, bought, built, weighed or tested.** This document separates the four
> things that are easy to confuse in a software-first project: defined interfaces, synthetic data, unselected
> hardware, and measurements that do not exist yet. The item-by-item audit is
> `HARDWARE_INTEGRATION_STATUS.md`; the generic hardware classes are `../avionics/HARDWARE_MAPPING.md`.
> ASTRA-66 is NOT FLIGHT CERTIFIED.

## 1. Software-defined interfaces (exist and are tested)

These are real, working software contracts. A hardware driver plugs in behind them without changing anything above.

| Interface | Contract | Defined in |
|---|---|---|
| `Sensor` | `name`, `rate_hz`, `simulated`; `due(t_us)`; `sample(t_us)` → `SensorSample` or `None`. **Input only** | `avionics/firmware/sensor_interfaces/base.py` |
| `LogSink` | `open(schema)`, `write(record)`, `flush()`, `close()` — a microSD writer implements this | `avionics/firmware/logging/logger.py` |
| `TelemetryLink` | `send(packet, t_s)`, `receive()`; the hardware link needs a radio driver with `transmit` / `receive` | `avionics/firmware/telemetry/link.py` |
| Flight-data schema | 23 fields with units, rates, plausibility limits and a CRC-16 per row (v1.1.0) | `avionics/data/schema/flight_data_schema.json` |
| Telemetry packet v2 | 41 bytes, little-endian, sequence number, CRC-16, SIMULATED flag, sensor-health bits | `avionics/firmware/telemetry/packet.py` |
| Data-source modes | `SYNTHETIC`, `BENCH`, `FLIGHT` (FLIGHT disabled until a real record exists) | `avionics/firmware/data_source.py` |
| Ground-station API | `GET /api/telemetry?after=N` → JSON frames, link statistics | `avionics/ground_station/server.py` |

A placeholder driver (`HardwareSensorPlaceholder`) refuses to return data, so simulated and real sources can never be
silently mixed, and the hardware telemetry link refuses to start without a radio driver.

## 2. Synthetic and test data (exist, clearly labelled)

| Dataset | What it is | Label |
|---|---|---|
| `avionics/data/example/example_flight_simulated.csv` | 4547 logged frames from the simulated sensors on the project trajectory (placeholder motor) | `SIMULATED` (legacy alias of SYNTHETIC) |
| `simulation/data/sample_flight.csv` | 2162-row sensor-level dataset with five scripted faults, for replay testing | `SYNTHETIC` |
| `avionics/bench_data/example_bench_record.csv` | Column template for future bench records; 501 rows of generated pad data | `SYNTHETIC` — explicitly *not* a measurement |
| `simulation/results/avionics_replay/` | Estimates, telemetry, log and event timeline from replaying the sample | derived from SYNTHETIC |

Rules that keep this honest: the mode is in every row, the logger refuses a frame whose mode differs from its own,
plots and reports print the mode, and `FLIGHT` is refused by the software.

## 3. Hardware not yet selected

Every item below is **COMPONENT TO BE SELECTED**. The repository names example classes only because the original BOM
listed them for planning; no datasheet has been checked and nothing has been bought.

Microcontroller · IMU · barometer · GNSS module and antenna · temperature sensor · battery-monitor divider ·
1S LiPo battery · 3.3 V regulator · power switch · microSD card and socket · telemetry radio pair (band and power
must be legal where operated) · buzzer and LED · optional camera · ground-station radio.

Selection procedure and per-subsystem requirements: `HARDWARE_SELECTION_CHECKLIST.md`.

## 4. Hardware that must be measured

Nothing in this repository has been measured. The following are needed before any of the "fits" or "mass" statements
mean anything physical:

1. Real board outlines **with headers and connectors**, against the CAD placeholder envelopes.
2. Mass of every avionics and payload item, and of each assembled module (currently all estimates:
   electronics 59 g, GPS 20 g, battery 27 g, camera 35 g, switch allowance 12 g).
3. Centre of gravity of the assembled vehicle (balance method plus a moment cross-check).
4. Tube, coupler and motor-tube diameters from the purchased stock (3 stations × 2 axes).
5. Avionics-bay sealing and static-port pressure lag.
6. Battery cell size, retention and pad endurance.
7. Harness: connector passage through the ⌀8 mm grommet, wire count, bend radius.
8. Radio: antenna placement, interference with GNSS, and usable range.
9. Printed-part fits (shoulder, fin guide slot, heat-set inserts) from fit coupons.

Procedure: `MASS_MEASUREMENT_PROCEDURE.md`. Open CAD-side warnings: `CAD_AVIONICS_INTEGRATION.md`.

## 5. Future physical validation

In order, and none of it has started:

1. Mentor-approved component selection, recorded with datasheet references.
2. Measure and weigh; update `cad/parts/COTS_envelopes.scad` and `analysis/analysis.py`; re-run the pipeline
   (including `--with-cad`) so the CAD, mass budget and simulation stay consistent.
3. Bench tests B-01…B-14 (`AVIONICS_BENCH_TEST_PLAN.md`), recording data as `BENCH` and replaying it through the same
   software.
4. Hardware-in-the-loop comparison: bench data versus the simulation, using the existing analysis tool.
5. Only then, and only with a qualified mentor and range approval: motor selection with published data, mass and CG
   with the motor fitted, flight-readiness review.

Until every one of those steps has evidence in the repository, ASTRA-66 remains a software and design project:
**NOT FLIGHT CERTIFIED**.

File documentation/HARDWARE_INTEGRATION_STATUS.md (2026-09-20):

# ASTRA-66 — Hardware-integration readiness status (Phase 6)

> **NOT FLIGHT CERTIFIED.** Nothing in ASTRA-66 has flown, no avionics hardware has been bought, built, weighed or
> tested, and no propulsion is designed here: the motor is an external, commercially certified component represented by
> PLACEHOLDER data. This document classifies what the repository actually establishes today, so a bench-validation
> phase can start without mistaking software results for measurements.

Categories used below:

| Tag | Meaning |
|---|---|
| **PASS** | Implemented and verified by the automated software tests (on synthetic data) |
| **ASSUMED** | Engineering assumption or requirement; defensible, but not measured |
| **UNVERIFIED** | Needs a physical measurement of the existing design |
| **REQUIRES HARDWARE** | Cannot be established at all until components exist on a bench |
| **REQUIRES MENTOR/RANGE REVIEW** | Needs a qualified rocketry mentor, or range / regulatory approval |

## 1. avionics/

| Item | Status | Evidence / next step |
|---|---|---|
| Sensor interface, scheduling, sample model | PASS | `avionics/tests/test_sensor_validation.py`; fixed-rate scheduling without drift |
| Schema validation (types, ranges, NaN, enums, required fields) | PASS | schema-driven; invalid values rejected before processing |
| Timestamp handling (wrap, duplicates, backwards, gaps) | PASS | `avionics/tests/test_timestamps.py` |
| Kalman estimator, barometer-only after apogee | PASS | tracks the synthetic truth within the documented tolerances |
| Flight-state classifier and events | PASS | forward-only; pad-knock and accelerometer-failure cases covered |
| Sensor health (stale detection) | PASS | `tests/test_avionics.py`; telemetry packet v2 carries the bits |
| Data logger, CSV / JSON-lines, CRC-16 rows, metadata | PASS | round trip and damaged-file handling tested |
| Telemetry packet v2, encode / decode, saturation, sentinels | PASS | every single-bit error rejected |
| Link statistics: loss, duplicates, rejects, wrap | PASS | `avionics/ground_station/receiver.py` + tests |
| Ground-station display and API | PASS (software) | prototype only; **REQUIRES HARDWARE** for real-time use |
| Post-flight analysis and derived statistics | PASS | checked against the synthetic truth profile |
| Data-source modes SYNTHETIC / BENCH / FLIGHT | PASS | `avionics/firmware/data_source.py`; FLIGHT disabled until real data exist |
| Sensor ranges, rates, thresholds, filter tuning | ASSUMED | `avionics/HARDWARE_MAPPING.md`, `avionics/firmware/sensor_interfaces/catalog.py` |
| Simulated noise, drift, discharge, parachute swing | ASSUMED (illustrative) | not properties of any component |
| Every component choice | REQUIRES HARDWARE | all COMPONENT TO BE SELECTED |
| Loop timing, SD write latency, power budget, radio range | REQUIRES HARDWARE | `documentation/AVIONICS_BENCH_TEST_PLAN.md` |
| Radio band, power and frequency coordination | REQUIRES MENTOR/RANGE REVIEW | must be legal where operated |

## 2. analysis/

| Item | Status | Evidence / next step |
|---|---|---|
| Parameter provenance tags and single source of truth | PASS | `analysis/analysis.py` is the only source of geometry and masses |
| Mass budget arithmetic, CG, CP (Barrowman), static margin | PASS | recomputed independently in `avionics/integration/cad_mass_integration.py`: identical |
| Structural part masses (CAD volume × assumed density × fill) | ASSUMED | densities and fill factors are assumptions; weigh the printed parts |
| Avionics masses EL-AV 59 g, EL-GPS 20 g, EL-BAT 27 g, camera 35 g, AV-309/310 12 g | ASSUMED / UNVERIFIED | weigh: `documentation/MASS_MEASUREMENT_PROCEDURE.md` |
| Measured CG of the built vehicle | UNVERIFIED | balance measurement after assembly |
| Static margin with a real motor | REQUIRES MENTOR/RANGE REVIEW | needs the certified motor's published data |

## 3. simulation/

| Item | Status | Evidence / next step |
|---|---|---|
| 1-DOF trajectory, ISA atmosphere, numerical verification | PASS | 13/13 verification checks |
| Sensor replay through the flight-computer pipeline | PASS | `simulation/avionics_replay.py` + synthetic sample dataset |
| Drag build-up coefficients | ASSUMED | cross-check with OpenRocket / RASAero; flight data would be needed to calibrate |
| Motor thrust curve, mass, burn time | ASSUMED (PLACEHOLDER) | replace with the certified motor's published data |
| Wind, weathercocking, angle of attack, dynamic stability | not modelled | out of scope of the 1-DOF model |
| Real trajectory behaviour | REQUIRES MENTOR/RANGE REVIEW | only a supervised flight can show it |

## 4. cad/

| Item | Status | Evidence / next step |
|---|---|---|
| Geometry, manifold meshes, interference, assembly feasibility | PASS | committed CAD validation: 147 PASS / 12 WARN / 0 FAIL |
| Electronics fit of the PLACEHOLDER envelopes (sled, battery, GPS, switch) | PASS | `documentation/CAD_AVIONICS_INTEGRATION.md` |
| Envelope completeness (buzzer, LED, regulator, temperature sensor, divider, wiring) | UNVERIFIED (WARN) | add envelopes when the parts are selected |
| IMU position relative to the roll axis | UNVERIFIED (WARN) | placeholder is 20.5 mm off axis; decide with the real board |
| Antenna routing and metal proximity | UNVERIFIED (WARN) | no antenna geometry modelled |
| Sled removal margin (0.40 mm on placeholders) | UNVERIFIED (WARN) | re-check with real boards, wires and connectors |
| Tube, coupler and MMT dimensions | UNVERIFIED | measure the purchased stock (3 stations × 2 axes) |
| Printed-part fit (shoulder, guide slot, inserts) | REQUIRES HARDWARE | print fit coupons |

## 5. documentation/

| Item | Status | Evidence / next step |
|---|---|---|
| File references and disclaimers in every document | PASS | `tests/test_docs.py`, `avionics/tests/test_architecture.py` |
| Engineering status generated from the result files | PASS | `documentation/ENGINEERING_STATUS.md` is regenerated by the pipeline |
| Hardware mapping, data format, bench plan, mass procedure | complete as plans | they describe work that has **not** been done yet |
| Flight-readiness review, range approval | REQUIRES MENTOR/RANGE REVIEW | the project is NOT flight certified |

## 6. tests/

| Item | Status | Evidence / next step |
|---|---|---|
| 40 project regression tests (package, CAD data, simulation, documentation) | PASS | part of the 74 run by `python -m unittest discover -s tests` |
| 34 avionics integration tests | PASS | `tests/test_avionics.py` |
| 81 avionics software tests | PASS | `python -m unittest discover -s avionics/tests -t .` |
| Safety-boundary guard (no actuation identifiers, no hardware-I/O imports) | PASS | `avionics/tests/test_architecture.py` |
| Any test against real sensors, radio or flight data | REQUIRES HARDWARE | the FLIGHT data-source mode stays disabled until a real record exists |

## 7. Summary

- **Software behaviour:** verified by 155 automated tests on synthetic data (74 project regression tests including
  34 avionics integration tests, plus 81 avionics software tests). This says nothing about hardware.
- **Physical properties:** every avionics mass, dimension and sensor property is ASSUMED or UNVERIFIED.
- **Bench validation:** planned in `documentation/AVIONICS_BENCH_TEST_PLAN.md`; needs components that do not exist yet.
- **Mentor / range review:** motor selection and data, radio legality, battery handling, mass and CG with the motor
  fitted, and the flight-readiness review.

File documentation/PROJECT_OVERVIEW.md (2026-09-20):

# ASTRA-66 — Project overview

> **Educational engineering project. NOT FLIGHT CERTIFIED.** Nothing here has flown, no avionics hardware has been
> selected, built, weighed or tested, and propulsion is an external, commercially certified component that is never
> designed in this repository (its data are placeholders). Every avionics dataset is synthetic.

ASTRA-66 system architecture

## 1. What ASTRA-66 is

ASTRA-66 is a 66 mm-class, 1144 mm modular student rocket airframe developed as a complete engineering project:
a parametric CAD model, a non-propulsion engineering analysis, a flight simulation, an avionics and flight-data
software framework, and an automated validation pipeline that ties them together. It is a **design and software
project**: the vehicle has not been built.

The repository is meant to be read as engineering work, not as a product. Every number carries its provenance, and
results that depend on assumptions or placeholders say so.

## 2. The engineering problem

Design a student-buildable rocket airframe that:

- stays statically stable through the flight (target 1.5–3.0 calibres of static margin);
- can be manufactured with a hobby FDM printer, laser-cut plywood and purchased tube stock;
- carries a data-only avionics payload (sensing, logging, telemetry) with **no** connection to anything energetic;
- uses an external, commercially certified motor chosen and handled by a qualified mentor;
- and can be checked automatically, so that a change to one parameter re-validates the whole design.

The hard part for a student project is not drawing the rocket: it is keeping analysis, CAD, simulation and software
consistent, and being honest about which numbers are verified, assumed or placeholders.

## 3. System architecture

| Layer | What it does | Where |
|---|---|---|
| Parameters | Single source of truth: geometry, materials, masses, with a provenance tag on every value | `analysis/analysis.py` |
| CAD | Parametric OpenSCAD model driven by the generated parameter file; exports meshes, cut files and drawings | `cad/` |
| Analysis | Mass budget, CG, Barrowman CP, static margin, loads, recovery sizing | `analysis/` |
| Simulation | 1-DOF trajectory, stability, sensitivity, numerical verification | `simulation/` |
| Avionics software | Sensor interface → validation → state estimation → flight state → logging and telemetry | `avionics/firmware/` |
| Ground station | Packet receiver, link statistics, browser dashboard (prototype, replay only) | `avionics/ground_station/` |
| Analysis of flight data | Tolerant log reader, plots, derived statistics | `avionics/analysis/` |
| Validation | One command that rebuilds, re-checks and tests everything; runs in CI | `run_validation.py` |

## 4. Software architecture

The avionics software is layered so that each layer talks to an interface, not to hardware:

```
Sensor (interface)  →  validation against the data schema  →  Kalman vertical-state estimator
                    →  flight-state classifier (labels only)  →  data logger (CSV/JSONL + CRC-16)
                                                              →  telemetry packet v2 → link → ground station
```

- Today the sensors are **simulated** or **replayed** from a recorded dataset; a real driver would implement the same
  `Sensor` interface, and nothing above it would change.
- The flight state is a **data label**. There is no actuator interface, and a test fails the build if an
  actuation-style identifier or a hardware-I/O import appears in the avionics code.
- Data carry a mode: `SYNTHETIC`, `BENCH` or `FLIGHT`. `FLIGHT` is disabled in software because no flight record
  exists.

Details: `AVIONICS_ARCHITECTURE.md`, `AVIONICS_DESIGN.md`, `../avionics/DATA_FORMAT.md`.

## 5. CAD workflow

1. `analysis/analysis.py` computes the geometry and writes `cad/astra66_params.scad`.
2. `cad/build_cad.py` renders the master assembly and every part with OpenSCAD, then measures the **rendered meshes**:
   volumes, centroids, bounding boxes, manifold checks, interference, assembly feasibility (for example whether the
   sled still slides out, or whether a fin can be removed with the retainer fitted).
3. It exports print and cut files, generates drawing sheets from true mesh sections, and writes
   `CAD_VALIDATION.md` plus a machine-readable validation record.
4. CAD-derived masses are handed back to the analysis, so the mass budget uses measured mesh volumes rather than
   hand estimates.

Current result: **147 PASS, 12 accepted WARN, 0 FAIL, 0 interferences**.

## 6. Simulation workflow

`simulation/flight_simulation.py` integrates a 1-DOF vertical trajectory (RK4, ISA atmosphere, drag build-up),
computes stability through the flight, runs a sensitivity study, and writes plots and reports. A separate
verification module checks the code against closed-form solutions and independent calculations: **13/13 checks pass**.

The motor is external data (`simulation/motor_config.json`). Its status is `PLACEHOLDER`, so the trajectory numbers
demonstrate the software and the sensitivities — they are **not predictions**.

## 7. Avionics and data workflow

1. A sensor source (simulated, or a recorded dataset replayed through `simulation/avionics_replay.py`) produces
   samples.
2. Every value is validated against the schema before processing: NaN, unparseable and out-of-range values never
   reach the estimator.
3. The estimator and classifier produce altitude, vertical velocity, flight state and events.
4. The logger writes schema-conformant CSV rows with a CRC-16 per row; the telemetry layer emits 41-byte packets with
   sequence numbers, CRC and sensor-health bits.
5. The ground station decodes packets, counts loss and shows the data; the post-flight tool re-reads a log tolerantly
   and produces plots and statistics.

## 8. Validation methodology

- **One command** (`python run_validation.py`) runs seven steps: package build, CAD currency (or a full re-render),
  simulation, sensor replay, CAD-fit and mass check, project regression tests, avionics software tests.
- **CI** runs the same command on Python 3.12 and 3.14 for every push and pull request.
- **Checksums** (`MANIFEST.sha256`) cover every tracked file.
- **Reproducibility** is a design rule: standard library only, deterministic formats, seeded synthetic data, no dates
  inside data files.

What this does and does not show is spelled out in `VALIDATION.md`.

## 9. Current limitations

- Propulsion data are placeholders; every trajectory value and any margin that includes the motor is provisional.
- No avionics hardware has been selected, built, weighed or tested; all avionics masses are estimates.
- Rail-exit speed (11.7 m/s with the placeholder motor) is below the usual 15 m/s guideline on the 1.0 m planning rail.
- Four CAD integration warnings remain (incomplete electronics envelopes, IMU placeholder off the roll axis, metal
  beside the radio, a 0.40 mm sled-removal margin), plus eight items that need physical measurement.
- The drag model is uncalibrated; the flight model is 1-DOF (no wind, weathercocking or dynamic stability).
- Structures rest on hand calculations with conservative allowables: no FEA, no coupon tests.
- Nothing physical has been verified. See `HARDWARE_INTEGRATION_STATUS.md` for the complete classification.

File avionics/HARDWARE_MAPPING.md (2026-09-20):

# ASTRA-66 avionics — hardware-agnostic interface map

> **No avionics hardware has been selected, bought, bench-tested or flown. The avionics are NOT flight certified.** This
> map links each logical software component to a generic class of commercially available, student-accessible hardware.
> Where the project already names a candidate class (`avionics/electronics.csv`, generated by `build.py`), it is kept
> as is; its datasheet values have **not** been checked. Nothing here is a validated part. Every item is
> **COMPONENT TO BE SELECTED** until a mentor-reviewed selection is recorded with datasheet references.

## 1. Map

Legend: **Required** / **Optional** follows the existing `build` column of `avionics/electronics.csv` ("both" =
required in both builds, "rec" = recommended build only). ✔ = applies.

| Logical component (software) | Generic hardware class | Existing candidate class (kept, datasheet not verified) | Interface | Required / Optional | Prototype assumption | Needs bench validation | Needs flight/range approval |
|---|---|---|---|---|---|---|---|
| Flight computer (`flight_computer.py`) | Low-power microcontroller board | RP2040 or ESP32-S3 dev board | — | **Required** | ✔ loop timing, memory and µs timer assumed adequate | ✔ loop rate, SD latency, power draw | ✔ as part of the flight-readiness review |
| IMU (`sensor_interfaces`, `imu`) | 6-axis (or 9-axis) digital IMU breakout | 6-axis ±32 g class breakout | I²C or SPI | **Required** | ✔ ≥ ±16 g, ≥ ±1000 deg/s, 100 Hz; axis mapping | ✔ bias, noise, saturation, mounting | ✔ via flight-readiness review |
| Barometer (`baro`) | Digital pressure sensor breakout | BMP390 or MS5611 class breakout | I²C or SPI | **Required** | ✔ 30–110 kPa, 50 Hz | ✔ noise, static-port lag, bay leak | ✔ via flight-readiness review |
| GNSS (`gnss`) | UART GNSS module + antenna | u-blox M8/M9/M10 class + patch antenna | UART | Optional | ✔ ≥ 1 Hz, fix after boost | ✔ time to fix, lock under the tube, interference from the radio | — |
| Temperature (`temperature`) | Digital temperature sensor, or the barometer's internal channel | TMP117 class breakout or barometer internal sensor | I²C | Optional | ✔ −20…+60 °C | ✔ self-heating | — |
| Battery monitor (`battery`) | ADC input + resistor voltage divider | none listed: added in Phase 4 (MCU ADC, divider values not chosen) | ADC | **Required** (Phase 4 requirement) | ✔ 0–5 V input range | ✔ divider calibration, sag under load | — |
| Battery | 1S LiPo with protection circuit | 1S LiPo, JST-PH, in AV-308 cage | power | **Required** | ✔ ≤ 28.8 mm wide; capacity for the pad hold | ✔ endurance on the pad (test T-10), retention | ✔ range rules on LiPo handling and charging |
| Power regulation | 3.3 V LDO or buck regulator | 3.3 V LDO or buck (≥ 500 mA) | power | **Required** | ✔ current budget | ✔ brown-out margin | — |
| Power switch AV-307 | Latching switch, externally accessible | COTS latching switch, screw or key type (BOM part AV-307, listed there as "arming switch"; it only switches power to the electronics) | power | **Required** (BOM) | ✔ fits the switch-band hole | ✔ cannot switch off under vibration | ✔ range procedures for switching electronics on at the pad |
| Storage (`logging`, `CsvLogSink`) | microSD card + SPI socket, or equivalent flash | microSD SPI breakout + high-endurance card | SPI | **Required** | ✔ sustained write ≥ log rate × ~110 B/row | ✔ write latency, power-loss behaviour, retention in vibration | — |
| Telemetry radio (`telemetry`, `HardwareTelemetryLink`) | Legal low-power telemetry radio module (pair) | Semtech SX127x LoRa module pair, **only on a band and power legal where used** | SPI | Optional | ✔ 41-byte packets at 5 Hz | ✔ link range and loss (test T-14), antenna placement | ✔ **frequency / power legality and range frequency coordination** |
| Separation sense | Breakwire loop + digital input | Thin enamel wire + 2-pin connector across I-03 | GPIO **input** only | **Required** | ✔ continuity logic | ✔ continuity and bounce (test T-15) | — |
| Buzzer + LED | Active piezo buzzer, status LED | Active piezo buzzer, status LED | GPIO (annunciation only) | **Required** | ✔ | ✔ audible on the pad / after landing | — |
| Camera | Self-contained action / FPV recorder | Mini recorder with its own battery (USER choice) | none (standalone) | Optional | ✔ mass 35 g placeholder | ✔ field of view through the ⌀14 mm hole | ✔ via flight-readiness review (mass, retention) |
| Ground station (`ground_station`) | Second radio module + MCU + USB to a laptop | 2nd LoRa module + MCU + USB (Python logger) | USB serial | Optional | ✔ | ✔ real-time display with real packets | ✔ same radio legality as above |

There is **no** actuator, igniter, pyrotechnic, energetic-device or deployment output in this map, and none may be
added: the flight computer only reads sensors and writes data. Recovery uses the certified motor's own ejection,
prepared by a mentor. Propulsion is an external, commercially certified component and is not part of the avionics.

## 2. Interface-requirement shortlist (what a candidate must satisfy)

These are **requirements for selection**, not specifications of any part. Ranges derived from the simulation use the
PLACEHOLDER propulsion input and must be re-derived with the certified motor's published data.

| Component | Must have | Should have | Check on the bench |
|---|---|---|---|
| Microcontroller | I²C + SPI + UART + ADC; free-running µs timer; enough RAM for SD buffering | open, maintained drivers for the chosen sensors; USB for configuration | 100 Hz loop with margin while logging and transmitting |
| IMU | accelerometer full scale ≥ ±16 g; gyro ≥ ±1000 deg/s; ≥ 100 Hz output; documented axis orientation | selectable anti-alias filter; FIFO | bias and noise at rest; axis mapping to +z nose |
| Barometer | 30–110 kPa range; ≥ 20 Hz (50 Hz preferred) | oversampling / IIR filter settings; temperature output | noise at rest; response through the 4 × ⌀2 mm static ports |
| GNSS | UART output of position, fix type and satellites at ≥ 1 Hz | ≥ 5 Hz; high-dynamics / airborne mode; external or patch antenna | cold / warm time to fix inside the airframe |
| Temperature | −20…+60 °C | 0.5 °C accuracy or better | offset against a reference; self-heating |
| Battery monitor | divider keeping the ADC input in range at 4.2 V | high-value divider (low drain) with calibration | reading vs a multimeter across 3.3–4.2 V |
| Storage | sustained writes above the log data rate; FAT-compatible | industrial / high-endurance card | 1 h continuous log; pull-power test (CRC-16 rows show the damage) |
| Radio | legal band and power where operated; SPI | configurable data rate; CRC in the modem | range walk test at ≥ 2× the expected distance (T-14) |
| Mechanical fit (all boards) | within the CAD envelopes and existing M2.5 bosses (`documentation/CAD_AVIONICS_INTEGRATION.md`) | IMU near the roll axis | measure each board with headers and connectors; weigh everything |

## 3. Status of every hardware assumption

| Assumption | Where it is used | Status |
|---|---|---|
| Sensor ranges and rates (§2) | `avionics/firmware/sensor_interfaces/catalog.py` | requirement (class C); not verified on hardware |
| Module envelopes and positions | `cad/parts/COTS_envelopes.scad` | PLACEHOLDER; CAD fit checked only for the placeholders |
| Avionics masses (EL-AV 59 g, EL-GPS 20 g, EL-BAT 27 g, switch allowance 12 g) | `analysis/analysis.py`, mass table in `avionics/integration/avionics_mass_properties.csv` | ASSUMPTION: weigh |
| Sensor noise, drift, discharge, swing | `avionics/firmware/sensor_interfaces/simulated.py` | illustrative (class D), not component properties |
| State thresholds and filter tuning | `avionics/firmware/flight_state/` | assumption, checked on simulated data only |
| Radio link margin, SD write speed, power budget | — | not assessed |

Next step for any item: select with a mentor → record the part and datasheet references → measure on the bench →
update the CAD envelope and the mass budget through the normal pipeline → re-run `python run_validation.py`.

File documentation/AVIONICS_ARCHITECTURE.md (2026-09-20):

# ASTRA-66 — Avionics architecture (Phase 5 audit and integration)

> **Draft student design. NOT flight certified.** The avionics are a data system only: they read sensors, estimate the
> vertical state, log, transmit telemetry and support analysis. There is no actuator, igniter, pyrotechnic, energetic
> or deployment output, no autonomous flight control, and no propulsion design; propulsion is an external,
> commercially certified component. No avionics hardware has been selected or tested, and every dataset is SIMULATED
> or synthetic. Phase 4 design: `documentation/AVIONICS_DESIGN.md`. Phase 5 status: `documentation/PHASE_5_STATUS.md`.

## 1. Block diagram

```
 SENSORS  IMU · barometer · GNSS · temperature · battery monitor · breakwire       (all COMPONENT TO BE SELECTED)
   │        today: simulated sensors (avionics/firmware/sensor_interfaces/simulated.py)
   │        or recorded / synthetic data (simulation/avionics_replay.py → ReplaySensor)
   ▼
 SENSOR ABSTRACTION        Sensor.sample(t_us) → SensorSample                        sensor_interfaces/base.py
   ▼
 FILTERING / VALIDATION    schema plausibility limits; NaN, inf, unparseable,       flight_computer.py (_validate)
                           out-of-range → rejected before processing; per-sensor
                           health = valid sample within 3 nominal periods
   ▼
 STATE ESTIMATION          pad reference pressure → ISA altitude → 2-state          flight_state/estimator.py
                           Kalman filter (altitude, vertical velocity);
                           barometer-only after apogee
   ▼
 FLIGHT-STATE / EVENT      PRELAUNCH → ASCENT → COAST → DESCENT → LANDED,           flight_state/classifier.py
 LOGIC                     events LIFTOFF / BURNOUT / APOGEE / LANDING (data labels; they drive nothing)
   ├──────────────────────────────────────────────┐
   ▼                                              ▼
 DATA LOGGER                                    TELEMETRY PACKET
 timestamp check, schema validation,            v2, 41 bytes, CRC-16, sequence number,
 quality flags, CSV / JSON-lines,               SIMULATED flag, sensor-health bits
 CRC-16 per row          logging/               → SimulatedTelemetryLink            telemetry/
   │                                            (hardware link: interface only)
   ▼                                              ▼
 microSD (hardware) / file (today)              GROUND STATION
   │ copied after recovery                      receiver (CRC, loss, duplicates, latest time) →
   ▼                                            server (JSON API) → dashboard       ground_station/
 POST-FLIGHT ANALYSIS          analysis/flight_data_analysis.py
```

The logger and the telemetry are parallel branches after the flight-state logic: the log keeps every frame at the log
rate; telemetry sends summaries of the latest valid values at 5 Hz. The graphic version of the same architecture is
`avionics/architecture/avionics_block_diagram.svg`.

## 2. Audit of the Phase 4 implementation

| Item | What exists | Where | Finding |
|---|---|---|---|
| Sensor interfaces | `Sensor` base class (fixed-rate scheduling, `sample(t_us)`), `HardwareSensorPlaceholder` that refuses to read, simulated sensors with fault injection | `avionics/firmware/sensor_interfaces/` | Sound. Phase 5 adds `ReplaySensor` for recorded data (no second interface) |
| IMU data model | 3-axis specific force (m/s²) and 3-axis rate (deg/s), body frame +z toward the nose, 100 Hz | schema, `simulated.py` | Sound. The CAD places the IMU envelope 20.5 mm off the roll axis, conflicting with the "near-axis" requirement (WARN in the CAD check) |
| Barometer data model | pressure (Pa) → altitude above the pad (ISA); pad reference = running mean, frozen at liftoff or when > 5 m above it | `estimator.py` | Sound. **New finding:** sea-level ISA temperature overestimates height above an elevated pad by ≈ 1.1 % at 500 m (documented in `avionics/DATA_FORMAT.md` §6; planning site is at 0 m) |
| GPS data model | latitude / longitude (deg), altitude MSL, fix, satellites at 1 Hz; position nulled without fix | schema, `avionics/firmware/flight_computer.py` | Sound; GNSS health (message received) is kept separate from fix quality |
| Temperature sensing | bay temperature (°C) at 1 Hz, logged and transmitted | schema | Logged only; not used in processing (it could later set the barometric reference temperature) |
| Battery-voltage monitoring | voltage (V) at 1 Hz, logged and transmitted | schema | No low-voltage logic on board (correct for a data system); Phase 5 ground station shows OK / LOW / CRITICAL with planning thresholds (assumptions) |
| SD / data logging | `DataLogger` + CSV / JSON-lines / memory sinks, metadata sidecar, tolerant reader | `avionics/firmware/logging/` | Sound. No SD-card driver (needs hardware) |
| CRC / checksum | CRC-16/CCITT-FALSE shared by log rows, JSON lines and packets | `avionics/firmware/crc.py` | Sound. Phase 5 test: every single-bit error in a packet is rejected |
| Packet / frame format | log frame = schema row; telemetry packet v1 (41 bytes, as built in Phase 4) | schema, `avionics/firmware/telemetry/packet.py` | Flag bits 3–7 were unused. **Phase 5: packet v2** carries sensor-health bits in them (same size; v1 still decodes) |
| Telemetry model | `SimulatedTelemetryLink` (seeded loss, bit errors), `HardwareTelemetryLink` (interface only), 5 Hz, latest values | `avionics/firmware/telemetry/link.py`, `avionics/firmware/flight_computer.py` | **Gap:** latest values were repeated when a sensor went silent, so a dead sensor looked alive. Fixed by the v2 health bits |
| Ground-station interface | receiver, HTTP JSON API, browser dashboard; capture replay and live simulation | `avionics/ground_station/` | Phase 5 adds sensor health, GPS / battery status, packet count and loss, latest telemetry time, and a sensor-replay source |
| State estimator | 2-state Kalman filter, accelerometer predict / barometer update, barometer-only after apogee | `estimator.py` | Sound. **Defect found:** only NaN / inf were filtered before processing, so a finite but impossible value (e.g. 250 kPa) would have corrupted the altitude estimate. Fixed: values are validated against the schema before processing |
| Event / state machine | forward-only classifier with confirmation times, barometric launch backup, BURNOUT_NOT_DETECTED | `classifier.py` | Sound; thresholds remain assumptions |
| Configuration system | fields and limits in `flight_data_schema.json`; sensor requirements and nominal rates in `catalog.py`; thresholds in `ClassifierConfig`; filter tuning in `VerticalKalmanFilter`; rates as `FlightComputer` arguments | several files | **Gap (documented, not changed):** no single avionics configuration file. A central config is recommended once hardware is selected; adding one now would only move assumptions around |
| Test coverage | 81 hardware-free tests in `avionics/tests/` | `avionics/tests/` | Phase 5 adds `tests/test_avionics.py` (integration: packets v2, validity, replay, ground station, CAD / mass report, documents) |

## 3. Phase 5 changes to the architecture (no redesign)

1. **Validation before processing** (`avionics/firmware/flight_computer.py`): every sample is checked against the
   schema; invalid values never reach the estimator, classifier or telemetry, while the raw value still goes to the
   logger, which writes it empty and flags it.
2. **Sensor health** (`FlightComputer.health()`): OK while a fully valid sample arrived within 3 nominal sample periods
   (assumption). Carried in telemetry packet v2 and in the replay outputs.
3. **Packet v2** (`avionics/firmware/telemetry/packet.py`): health bits in the previously unused flag bits; the
   decoder accepts v1 and v2.
4. **Receiver statistics** (`avionics/ground_station/receiver.py`): packet-loss percentage and latest packet time.
5. **Sensor replay** (`simulation/avionics_replay.py`): recorded / synthetic sensor data through the unchanged pipeline;
   deterministic sample `simulation/data/sample_flight.csv` (synthetic test data, not flight data).
6. **Ground-station data view** (`avionics/ground_station/dashboard/index.html`, `server.py --sensors`).
7. **CAD ↔ avionics and mass check** (`avionics/integration/cad_mass_integration.py`), read-only against the CAD and
   the analysis.

## 4. Value classes in this architecture

Nothing here is a measurement: the software behaviour is **verified by tests on synthetic data**, the sensor ranges,
rates and thresholds are **assumptions**, every component is **COMPONENT TO BE SELECTED**, and the physical fit and
masses are **UNVERIFIED until measured**. Which items sit in which class:
`documentation/HARDWARE_INTEGRATION_STATUS.md`.

## 5. Interfaces and formats

- Hardware classes, required / optional status and validation needs: `avionics/HARDWARE_MAPPING.md`.
- Every file and packet format with units and ranges: `avionics/DATA_FORMAT.md`.
- Sensor, software and physical interfaces: `avionics/architecture/interface_spec.md`.
- CAD fit and mass properties: `documentation/CAD_AVIONICS_INTEGRATION.md`.

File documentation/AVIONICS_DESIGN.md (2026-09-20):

# ASTRA-66 — Avionics and flight-data system design (Phase 4)

> **Draft student design. NOT flight certified.** This phase covers sensing, data logging, telemetry, ground-station
> visualisation and post-flight analysis only. The avionics have **no output of any kind** that could drive an
> igniter, pyrotechnic, energetic or deployment device. Propulsion is an external, commercially certified component,
> never designed here; recovery uses the certified motor's own ejection, prepared by a mentor. No avionics component has
> been selected, built or tested: every hardware item is **COMPONENT TO BE SELECTED**, and every dataset in this phase
> is **SIMULATED**. Any use in flight requires hardware testing and review by a qualified mentor and the range.

## 1. Scope and status

| Area | Status | Basis |
|---|---|---|
| Architecture (6 layers) | Defined | `avionics/architecture/system_architecture.md`, block diagram `avionics/architecture/avionics_block_diagram.svg` |
| Interfaces | Specified as requirements | `avionics/architecture/interface_spec.md` |
| Flight-data schema | Version 1.1.0, draft (1.0.0 in Phase 4; Phase 6 added the data-source modes) | `avionics/data/schema/flight_data_schema.json` |
| Flight-computer software | Implemented in Python, simulated sensors only | `avionics/firmware/` |
| Ground station | Prototype, simulated / replayed data only | `avionics/ground_station/` |
| Post-flight analysis | Implemented | `avionics/analysis/flight_data_analysis.py` |
| Tests | Hardware-free, run by `python run_validation.py` and CI | `avionics/tests/` |
| Hardware | **Nothing selected** | — |

Value classes as in the rest of ASTRA-66: the software's behaviour is **verified by test** on simulated data; sensor
ranges, rates, thresholds and filter tuning are **assumptions** (class C); simulated sensor noise, drift, discharge and
swing are **placeholders** (class D); nothing is **measured**.

## 2. Architecture

Six layers, each behind a hardware-independent interface (details in `avionics/architecture/system_architecture.md`):

1. **SENSOR LAYER**: `Sensor` interface, fixed-rate scheduling, simulated sensors with fault injection.
2. **FLIGHT-DATA PROCESSING**: pad reference, pressure → altitude, Kalman filter, flight-state classifier.
3. **DATA LOGGER**: timestamp checks, schema validation, quality flags, CSV / JSON-lines with CRC-16.
4. **TELEMETRY**: 41-byte packet, simulated link, hardware-link interface.
5. **GROUND-STATION VISUALIZATION**: receiver with link statistics, local server, dashboard.
6. **POST-FLIGHT ANALYSIS**: tolerant reader, plots, derived statistics.

The flight computer (`avionics/firmware/flight_computer.py`) ticks at 100 Hz, logs at 50 Hz (example; ≥ 100 Hz is
the hardware target) and sends telemetry at 5 Hz. Its only outputs are the log and the telemetry link.

## 3. Sensor strategy

| Sensor | Why it is needed | Primary / backup role | Requirement (assumption) |
|---|---|---|---|
| IMU | Liftoff, burnout, acceleration record | Primary for liftoff and burnout | accel ≥ ±16 g, gyro ≥ ±1000 deg/s, 100 Hz |
| Barometer | Altitude, apogee, landing | Primary for apogee and landing; **backup for liftoff** | 30–110 kPa, 50 Hz |
| GPS / GNSS | Recovery position, ground track | Independent altitude cross-check | ≥ 1 Hz |
| Temperature | Environment record | — | −20 to +60 °C, 1 Hz |
| Battery monitor | Endurance, brown-out diagnosis | — | 0–5 V ADC input, 1 Hz |
| Separation breakwire | Confirms separation at I-03 | Independent of the barometer | GPIO input, 50 Hz |

Redundancy is by **physics**, not duplication: liftoff can be detected by the accelerometer or, if it fails, by the
barometer; apogee by velocity sign or altitude drop; separation by the breakwire. All ranges derived from the
simulation use the **PLACEHOLDER** propulsion input (peak 7.4 g) and must be re-derived with the certified motor's
published data. The required ranges are not manufacturer specifications; candidate classes come from
`avionics/electronics.csv` and their datasheets have not been checked.

## 4. Data flow

Sensor → acquisition (µs timestamp) → processing (estimator, classifier) → logger (validation → CSV + CRC) → SD card
→ post-flight analysis; in parallel, latest values → telemetry packet → link → ground station. Frames carry only
samples taken since the previous frame (slow sensors appear about once per second); telemetry always carries the
latest values. Full description, rates and the error-handling table: `avionics/architecture/data_flow.md`.

## 5. Software architecture

| Package | Modules |
|---|---|
| `avionics/firmware/sensor_interfaces/` | `base.py` (interface), `catalog.py` (requirements), `simulated.py` (truth profiles, simulated sensors, faults) |
| `avionics/firmware/flight_state/` | `estimator.py` (Kalman filter), `classifier.py` (states) |
| `avionics/firmware/logging/` | `schema.py`, `timebase.py`, `logger.py`, `reader.py` |
| `avionics/firmware/telemetry/` | `packet.py`, `link.py` |
| `avionics/firmware/` | `flight_computer.py`, `simulate_flight.py`, `crc.py` |
| `avionics/ground_station/` | `receiver.py`, `server.py`, `avionics/ground_station/dashboard/index.html` |
| `avionics/analysis/` | `flight_data_analysis.py` |

**State estimator.** A 2-state Kalman filter (altitude, vertical velocity) predicts with the axial specific force minus
gravity and corrects with barometric altitude. This assumes nose-up vertical flight, as in the 1-DOF simulation. After
apogee the filter becomes barometer-only because the bay hangs at an unknown angle under the parachute. The pad
reference pressure is a running mean on the pad, frozen at liftoff or as soon as a reading is more than 5 m above it.

**Flight states (data processing only).** Forward-only sequence PRELAUNCH → ASCENT → COAST → DESCENT → LANDED. The
state is written to the log and telemetry and used by the analysis; it drives nothing.

| Transition | Rule (all thresholds are assumptions) | Rationale |
|---|---|---|
| PRELAUNCH → ASCENT | axial specific force > 2.0 g for 0.05 s, or altitude > 15 m with vertical velocity > 5 m/s for 0.05 s | thrust gives a clear step (placeholder average T/W 6.5); the time filter rejects handling knocks; barometric backup if the IMU fails |
| ASCENT → COAST | axial specific force < 0.5 g for 0.05 s, ≥ 0.2 s after liftoff | thrust gone, drag decelerates the vehicle |
| COAST → DESCENT | vertical velocity < −1 m/s for 0.25 s, or altitude 5 m below maximum; ≥ 2 s after liftoff | apogee; lockout against early transients |
| DESCENT → LANDED | abs(vertical velocity) < 1 m/s and altitude within 2 m for 3 s; ≥ 1 s after apogee | stationary on the ground |

If burnout is never seen (accelerometer failure), ASCENT goes directly to DESCENT on the apogee rule and the event
"BURNOUT_NOT_DETECTED" is recorded. Labels appear after the confirmation time; the analysis subtracts it to estimate
the event times.

## 6. Data schema

`avionics/data/schema/flight_data_schema.json`, version 1.1.0 (draft; 1.0.0 in Phase 4). One CSV row per logged frame; column order as
below; an empty cell means no fresh sample or a rejected value. `valid_range` values are **plausibility limits used by
validation, not sensor specifications**.

| Field | Type | Unit | Nominal rate | Source | Description |
|---|---|---|---|---|---|
| `seq` | int | count | log rate | flight computer | frame counter (gaps reveal lost frames) |
| `timestamp` | float | s | log rate | µs clock | time since clock start (required) |
| `data_source` | enum | — | log rate | flight computer | SIMULATED or HARDWARE (required) |
| `flight_state` | enum | — | log rate | classifier | PRELAUNCH / ASCENT / COAST / DESCENT / LANDED (data label only) |
| `imu_accel_x` | float | m/s² | 100 Hz | IMU | specific force, body x |
| `imu_accel_y` | float | m/s² | 100 Hz | IMU | specific force, body y |
| `imu_accel_z` | float | m/s² | 100 Hz | IMU | specific force, body z (axial, toward the nose; +9.81 on the pad) |
| `gyro_x` | float | deg/s | 100 Hz | IMU | angular rate about x |
| `gyro_y` | float | deg/s | 100 Hz | IMU | angular rate about y |
| `gyro_z` | float | deg/s | 100 Hz | IMU | angular rate about z (roll) |
| `barometric_pressure` | float | Pa | 50 Hz | barometer | static pressure |
| `altitude` | float | m | 50 Hz | barometer (derived) | altitude above the pad reference (ISA) |
| `vertical_velocity` | float | m/s | log rate | estimator | Kalman-filter vertical velocity |
| `temperature` | float | °C | 1 Hz | temperature sensor | bay temperature |
| `latitude` | float | deg | 1 Hz | GNSS | WGS84 (empty without fix) |
| `longitude` | float | deg | 1 Hz | GNSS | WGS84 (empty without fix) |
| `gps_altitude` | float | m | 1 Hz | GNSS | altitude above mean sea level |
| `gps_fix` | int | — | 1 Hz | GNSS | 0 none, 2 = 2D, 3 = 3D |
| `gps_satellites` | int | count | 1 Hz | GNSS | satellites used |
| `battery_voltage` | float | V | 1 Hz | battery monitor | 1S LiPo terminal voltage |
| `separation_detected` | int | 0/1 | 50 Hz | breakwire | separation at I-03 (logging only) |
| `quality_flags` | int | bitmask | log rate | logger | bit 0 accel, 1 gyro, 2 baro, 3 temperature, 4 GNSS, 5 battery value rejected; 6 timestamp gap |
| `crc16` | hex | — | log rate | logger | CRC-16/CCITT-FALSE of the row's other fields |

Example dataset: `avionics/data/example/example_flight_simulated.csv` (4547 frames, SIMULATED, replay of the existing
trajectory with the PLACEHOLDER propulsion input) with `avionics/data/example/example_flight_simulated.meta.json` and a
telemetry capture.

## 7. Telemetry

Packet v2 (41 bytes, little-endian, fixed point, CRC-16; Phase 5 added sensor-health flags, v1 still decodes): time,
sequence number, flags (SIMULATED, GPS valid, separation, IMU / barometer / GNSS / temperature / battery health), flight
state, altitude, vertical velocity, axial and total acceleration, temperature, latitude, longitude, GNSS altitude, fix,
satellites, battery voltage. Missing values have sentinels; out-of-range values saturate.
**SIMULATED TELEMETRY** (`SimulatedTelemetryLink`, seeded loss and bit errors) is implemented and used by the ground
station. **REAL HARDWARE TELEMETRY** (`HardwareTelemetryLink`) is an interface only and refuses to start without a
radio driver; no radio has been selected, and any radio must use a legal band and power level.

## 8. Ground station and post-flight analysis

- **Ground station** (`avionics/ground_station/`): decodes packets, counts rejected / missing / duplicate packets and
  shows flight state, altitude, vertical velocity, acceleration, temperature, GPS position and track, and battery
  voltage. Sources: a telemetry capture or a fresh simulated flight. Prototype only; **real-time flight capability is
  not claimed** and has not been tested.
- **Post-flight analysis** (`avionics/analysis/flight_data_analysis.py`): reads a log tolerantly and produces
  altitude, velocity, acceleration, temperature and battery plots against time, a GPS track, and derived statistics
  (apogee, maximum velocity and acceleration, descent rate, event times and durations, temperature and battery ranges,
  GNSS distances, data quality). Example output: `avionics/analysis/results/example_flight_simulated/flight_report.md`.

Example results (**SIMULATED, PLACEHOLDER propulsion; they show that the software works, not how a real flight would
behave**): detected apogee 328.3 m against 328.2 m in the source trajectory; liftoff, burnout, apogee and landing
detected within 0.05, 0.03, 0.01 and 0.2 s of the trajectory's events; descent rate 5.12 m/s against 5.09 m/s.

## 9. Testing strategy

All tests run without hardware (`python -m unittest discover -s avionics/tests -t .`, also step 5 of
`python run_validation.py` and therefore GitHub Actions).

| Test module | Covers |
|---|---|
| `avionics/tests/test_sensor_validation.py` | schema validation (non-finite, out-of-range, unparseable, enum, required fields), sensor catalogue, simulated sensors, fault injection, scheduling |
| `avionics/tests/test_timestamps.py` | 32-/16-bit counter unwrap, duplicate / backwards / gap detection, periodic frame times |
| `avionics/tests/test_missing_corrupt.py` | CRC-detected bit flips, truncated and garbage lines, out-of-order and duplicate rows, bad values, missing columns, sensor dropouts and NaNs in flight, barometer failure |
| `avionics/tests/test_flight_state.py` | state sequence and event timing on the synthetic profile and on the replayed trajectory, forward-only states, pad knock rejection, barometric backup, offline classification, estimator accuracy |
| `avionics/tests/test_telemetry.py` | CRC check value, packet round trip and quantisation, missing values, saturation, corruption detection, seeded link, hardware-link refusal, receiver statistics and sequence wrap |
| `avionics/tests/test_logger.py` | CSV and JSON-lines output with CRC, metadata sidecar, source labelling, freshness rule, validity and reproducibility of the committed example |
| `avionics/tests/test_analysis.py` | numerical helpers, derived statistics against the truth profile, output files, missing GNSS, offline states, committed example results |
| `avionics/tests/test_architecture.py` | **safety boundary** (no actuation identifiers, no hardware-I/O libraries), documentation paths and disclaimers, block diagram, ground-station server |

Tests compare with known truth (the simulated trajectory) using stated tolerances; none of them uses flight data,
because none exists.

## 10. Hardware-selection criteria (for the next phase, with a mentor)

1. **Safety boundary first:** no part may add an output able to drive an energetic or deployment device; the avionics
   stay sense-and-record only.
2. **Measurement range with margin** over the certified motor's data (re-derive the ≥ 16 g accelerometer requirement).
3. **Rates:** IMU ≥ 100 Hz, barometer ≥ 20 Hz (50 Hz preferred), GNSS ≥ 1 Hz, with a microcontroller that sustains the
   loop and SD writes with margin.
4. **Fit:** within the CAD placeholder envelopes and existing bosses (`avionics/architecture/interface_spec.md` §3), and
   within the mass allocation (EL-AV 59 g, EL-GPS 20 g, EL-BAT 27 g, assumptions); otherwise update the CAD and the
   analysis through the normal pipeline.
5. **Power:** 1S LiPo endurance for the pad hold with margin (measure; test T-10 in the engineering package).
6. **Availability and documentation:** student-accessible modules with published datasheets and open drivers; verify
   every figure from the datasheet, never from this repository.
7. **Radio legality:** only a band and power level legal where it is operated.

## 11. Limitations

- No hardware exists; every sensor, the microcontroller, the SD card and the radio are COMPONENT TO BE SELECTED.
- All data are SIMULATED. Sensor noise, drift, parachute swing, GNSS drift and battery discharge are illustrative
  placeholders; the truth trajectory uses the PLACEHOLDER propulsion input.
- Thresholds and filter tuning are assumptions, checked only against simulated data.
- The estimator assumes vertical flight until apogee (as the 1-DOF simulation); tilt, weathercocking and wind are not
  modelled; the gyroscopes are logged but not used for attitude estimation.
- The derived velocity in the analysis is smoothed and underestimates sharp peaks by a few m/s.
- The Python reference implementation has not been ported or timed on a microcontroller; SD-card write latency, radio
  range, power consumption and electromagnetic compatibility are not assessed.
- The ground station has not been tested with a real radio or in real time.
- The temperature sensor and battery divider have no CAD envelope yet.

## 12. Future hardware integration

1. Select components with a mentor against §10; record the selected part numbers and datasheet values (class A/C) in
   `avionics/firmware/sensor_interfaces/catalog.py` and `avionics/architecture/interface_spec.md`.
2. Update the CAD envelopes in `cad/parts/COTS_envelopes.scad` and the masses in `analysis/analysis.py`, then run the
   normal CAD and validation pipeline.
3. Write one driver per sensor behind the `Sensor` interface, an SD-card `LogSink` and a radio driver for
   `HardwareTelemetryLink`, keeping the data-source label HARDWARE only for real sensors.
4. Bench tests (engineering package T-10, T-14, T-15): sensor plausibility, logging rate, SD integrity, link range,
   breakwire logging. Compare against the simulation with the same analysis tool.
5. Re-derive thresholds with the certified motor's published thrust data; re-run all tests.
6. Mentor and range review before any flight consideration. The avionics remain a data system with no command outputs.

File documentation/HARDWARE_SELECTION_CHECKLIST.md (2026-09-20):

# ASTRA-66 — Hardware selection checklist (Phase 6)

> **No component has been selected, bought or tested, and the project is NOT flight certified.** This checklist turns
> `avionics/HARDWARE_MAPPING.md` into a per-subsystem selection sheet. It contains **no manufacturer part numbers**:
> where the repository already names an example class, that class is quoted with its source, and its datasheet has not
> been checked. Fill a sheet in only from a real datasheet, with a mentor.
>
> **Source of the existing example classes:** `avionics/electronics.csv`, generated by `build.py` from
> `documentation/generator/data_tables.py`. They are planning examples ("verify datasheets"), not selections.
> Mass figures below are the current **assumptions** in `analysis/analysis.py` (see
> `avionics/integration/avionics_mass_properties.csv`), not measurements.

How to use: copy a block per subsystem into the team's selection record, fill every row from the datasheet, then run
the bench tests in `documentation/AVIONICS_BENCH_TEST_PLAN.md`. A subsystem is "selected" only when every **evidence**
row is satisfied and a mentor has reviewed it. Until then it stays **COMPONENT TO BE SELECTED**.

## Common constraints (apply to every subsystem)

| Constraint | Value | Status |
|---|---|---|
| Logic voltage | 3.3 V (regulated); 1S LiPo 3.0–4.2 V upstream | assumption (`avionics/HARDWARE_MAPPING.md`) |
| 5 V-only parts | not acceptable without a documented level-shift / boost plan | assumption |
| Buses available | I²C, SPI, UART, ADC, GPIO **inputs** | design requirement |
| Outputs | **none**: no igniter, pyrotechnic, energetic or deployment channel may exist | safety boundary |
| Mounting | M2.5 inserts on the sled (10 bosses, 25 mm pitch) or the GPS tray (6 bosses) | CAD (`cad/parts/AV-306_electronics_sled.scad`) |
| Envelope | inside the coupler bore: sled stack max radius 30.5 mm | CAD check |
| Environment | −20…+60 °C assumed; vibration and shock not characterised | assumption |
| Documentation | public datasheet + open driver; record both in the selection sheet | requirement |

## 1. Flight computer (microcontroller board)

| Item | Requirement |
|---|---|
| Required interface | I²C + SPI + UART + ADC + GPIO inputs; free-running microsecond timer |
| Voltage / interface constraints | 3.3 V logic; USB for configuration; must not require 5 V sensors |
| Physical envelope | ≤ 21 × 8.5 × 50 mm placeholder (`cad/parts/COTS_envelopes.scad`), measure the real board with headers |
| Approximate mass budget | part of EL-AV 59 g total (assumption, covers MCU + IMU + baro + SD + radio + buzzer + wiring) |
| Mounting | M2.5 standoffs on the sled; connectors reachable with the sled fitted |
| Software interface | runs the Phase 4/5 pipeline structure (`avionics/firmware/flight_computer.py`) |
| Test required | B-01 power-up, B-02 sensor detection, B-11 timestamp consistency, B-13 long-duration logging |
| Evidence before flight use | measured loop rate ≥ 100 Hz with logging and telemetry active; measured current draw; weighed mass |
| Existing example class | "RP2040 (e.g. Raspberry Pi Pico) or ESP32-S3 dev board" — `avionics/electronics.csv`, unverified |

## 2. IMU (accelerometer + gyroscope)

| Item | Requirement |
|---|---|
| Required interface | I²C or SPI (SPI preferred at 100 Hz) |
| Voltage / interface constraints | 3.3 V; documented axis orientation; configurable full scale and output rate |
| Physical envelope | ≤ 14 × 4 × 14 mm placeholder; **placeholder position is 20.5 mm off the roll axis** — decide the final position |
| Approximate mass budget | within EL-AV 59 g (assumption) |
| Mounting | rigid, close to the roll axis if possible, axis mapping recorded in the firmware |
| Software interface | `Sensor` driver returning `imu_accel_x`, `imu_accel_y`, `imu_accel_z` (m/s², specific force) and `gyro_x`, `gyro_y`, `gyro_z` (deg/s) |
| Test required | B-03 IMU sanity (1 g checks, six orientations), B-11 timestamp consistency |
| Evidence before flight use | measured bias and noise at rest; full-scale ≥ ±16 g confirmed from the datasheet; axis mapping verified |
| Existing example class | "6-axis, ±32 g accel class (e.g. ST LSM6DSO32 breakout)" — `avionics/electronics.csv`, unverified |

## 3. Barometric pressure sensor

| Item | Requirement |
|---|---|
| Required interface | I²C or SPI |
| Voltage / interface constraints | 3.3 V; 30–110 kPa range; ≥ 20 Hz (50 Hz preferred) |
| Physical envelope | ≤ 13 × 4 × 13 mm placeholder, at the static-port station (STA 529 mm) |
| Approximate mass budget | within EL-AV 59 g (assumption) |
| Mounting | in the sealed avionics bay, shielded from light and draughts; 4 × ⌀2 mm static ports |
| Software interface | `Sensor` driver returning `barometric_pressure` (Pa) |
| Test required | B-04 pressure sanity (ambient, altitude change, syringe / bag test), B-13 |
| Evidence before flight use | measured noise at rest; measured pad-reference stability; documented static-port response |
| Existing example class | "Bosch BMP390 or TE MS5611 breakout" — `avionics/electronics.csv`, unverified |

## 4. GNSS receiver + antenna

| Item | Requirement |
|---|---|
| Required interface | UART (NMEA or documented binary protocol), ≥ 1 Hz |
| Voltage / interface constraints | 3.3 V logic; antenna connector and ground-plane needs documented; backup battery for warm start optional |
| Physical envelope | ≤ 25 × 8 × 35 mm placeholder on the payload tray, under the hatch |
| Approximate mass budget | EL-GPS 20 g including the antenna (assumption) |
| Mounting | 6 M2.5 bosses on `cad/parts/PL-202_gps_tray.scad`; sky view forward, away from the radio antenna |
| Software interface | `Sensor` driver returning `latitude`, `longitude`, `gps_altitude`, `gps_fix`, `gps_satellites` |
| Test required | B-05 GNSS acquisition (cold and warm, indoors / outdoors, inside the airframe) |
| Evidence before flight use | measured time to first fix; fix kept with the radio transmitting; weighed mass |
| Existing example class | "u-blox M8/M9/M10-class module + patch antenna" — `avionics/electronics.csv`, unverified |

## 5. Temperature sensor

| Item | Requirement |
|---|---|
| Required interface | I²C, or the barometer's internal temperature channel |
| Voltage / interface constraints | 3.3 V; −20…+60 °C |
| Physical envelope | no CAD envelope yet — add one if a separate breakout is chosen |
| Approximate mass budget | within EL-AV 59 g (assumption) |
| Mounting | in air, away from self-heating parts (regulator, radio) |
| Software interface | `Sensor` driver returning `temperature` (°C) |
| Test required | B-02 sensor detection, B-13 (drift over a long log) |
| Evidence before flight use | offset against a reference thermometer; self-heating measured |
| Existing example class | "TI TMP117 breakout or baro internal sensor" — `avionics/electronics.csv`, unverified |

## 6. Battery monitor

| Item | Requirement |
|---|---|
| Required interface | ADC input through a resistor divider |
| Voltage / interface constraints | divider must keep the ADC input inside its range at 4.2 V; high resistance to limit drain |
| Physical envelope | on the flight-computer board or a small adapter; no separate envelope yet |
| Approximate mass budget | negligible; inside EL-AV 59 g (assumption) |
| Mounting | as close to the battery connector as practical |
| Software interface | `Sensor` driver returning `battery_voltage` (V) |
| Test required | B-12 battery monitoring (calibration against a multimeter, sag under transmit) |
| Evidence before flight use | calibration curve recorded; resolution and drift stated |
| Existing example class | none: added in Phase 4 as a requirement |

## 7. Battery and power

| Item | Requirement |
|---|---|
| Required interface | 1S LiPo with protection circuit, JST-PH; 3.3 V regulator (≥ 500 mA) downstream |
| Voltage / interface constraints | 3.0–4.2 V; regulator must hold 3.3 V at the peak transmit current |
| Physical envelope | ≤ 28.8 mm wide (rod sleeves); placeholder cell 55 × 28 × 9 mm |
| Approximate mass budget | EL-BAT 27 g including the strap (assumption) |
| Mounting | `cad/parts/AV-308_battery_cage.scad`, strap-retained; connector reachable |
| Software interface | none (monitored through the battery monitor) |
| Test required | B-01 power-up, B-12 battery monitoring, B-13 endurance (existing test plan item T-10) |
| Evidence before flight use | measured pad-hold endurance with margin; retention checked under shake; charging procedure agreed |
| Mentor / range | LiPo handling, charging and transport follow the range's rules (**REQUIRES MENTOR/RANGE REVIEW**) |

## 8. Data storage (microSD or equivalent)

| Item | Requirement |
|---|---|
| Required interface | SPI socket; FAT-compatible card |
| Voltage / interface constraints | 3.3 V; sustained write above log rate × ~110 bytes per row (≥ 11 kB/s at 100 Hz) with margin |
| Physical envelope | ≤ 20 × 4.5 × 26 mm placeholder; card must be removable or the sled must come out |
| Approximate mass budget | within EL-AV 59 g (assumption) |
| Mounting | card slot orientation must not fight the sled removal direction |
| Software interface | `LogSink` implementation writing the schema CSV with CRC-16 rows |
| Test required | B-06 data logging, B-13 long-duration logging, B-14 power-down / data preservation |
| Evidence before flight use | no dropped frames over the longest planned log; damaged-row behaviour after a power cut |
| Existing example class | "microSD SPI breakout + industrial / high-endurance card" — `avionics/electronics.csv`, unverified |

## 9. Telemetry radio (optional subsystem)

| Item | Requirement |
|---|---|
| Required interface | SPI; 41-byte packets at 2–5 Hz |
| Voltage / interface constraints | 3.3 V; **band and power must be legal where the rocket is flown**; antenna impedance and length documented |
| Physical envelope | ≤ 20 × 7 × 28 mm placeholder; antenna route not modelled (steel rods run alongside) |
| Approximate mass budget | within EL-AV 59 g (assumption) for the airborne module |
| Mounting | module on the sled; antenna away from the rods, battery and GNSS antenna |
| Software interface | radio driver behind `HardwareTelemetryLink` (`transmit` / `receive`) |
| Test required | B-07 packet generation, B-08 packet integrity, B-09 ground-station link, B-10 packet-loss handling, and a range walk test (existing plan item T-14) |
| Evidence before flight use | measured packet-loss rate at ≥ 2× the expected distance; licence / band legality confirmed |
| Mentor / range | **REQUIRES MENTOR/RANGE REVIEW**: frequency coordination and power limits |
| Existing example class | "Semtech SX127x LoRa module pair — ONLY on a band/power legal in your country" — `avionics/electronics.csv` |

## 10. Separation sense, annunciation, camera

| Item | Requirement |
|---|---|
| Separation breakwire | thin wire across joint I-03 into a GPIO **input** with pull-up; test B-02 continuity, plan item T-15 |
| Buzzer + LED | GPIO annunciation only; audible after landing; test B-01 |
| Camera (optional) | self-contained recorder with its own battery, in `cad/parts/PL-203_camera_cradle.scad`; mass placeholder 35 g (USER); no electrical connection to the flight computer |

## Selection sheet (copy per subsystem)

```
Subsystem:                     ............................................
Candidate (make / model):      ............................................
Datasheet reference (URL, rev):............................................
Key figures taken from datasheet: range ......  rate ......  voltage ......
Interface / bus:               ............................................
Measured mass (g):             ......  (scale, resolution, date)
Measured size (mm):            ......  incl. headers and connectors
CAD envelope updated?          yes / no   (COTS_envelopes.scad, re-run CAD validation)
Mass budget updated?           yes / no   (analysis/analysis.py, re-run the pipeline)
Bench tests passed:            B-.. , B-.. (attach bench record file names)
Open issues:                   ............................................
Mentor review (name, date):    ............................................
Status:                        CANDIDATE / SELECTED / REJECTED
```

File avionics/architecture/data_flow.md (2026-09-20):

# ASTRA-66 avionics: data flow

All data described here are **synthetic** until hardware exists; ASTRA-66 is NOT flight certified. Schema:
`avionics/data/schema/flight_data_schema.json`.

## 1. End-to-end path

```
sensor (simulated today)
  │  SensorSample(sensor, t_us, values)             SENSOR LAYER
  ▼
acquisition: fixed-rate schedule, µs timestamp, freshness tracking
  │
  ├─► processing: pad reference → altitude → Kalman filter → state classifier     FLIGHT-DATA PROCESSING
  │
  ├─► frame (fresh samples + seq, timestamp, vertical_velocity, flight_state)
  │     └─► DataLogger: timestamp check → schema validation → quality flags → CSV / JSON-lines (+CRC-16)   DATA LOGGER
  │           └─► microSD card (hardware) / file (today) ─► copied after recovery ─► POST-FLIGHT ANALYSIS
  │
  └─► telemetry frame (latest values) → 41-byte packet v2 (+CRC-16, SIMULATED flag, sensor health) → link          TELEMETRY
        └─► ground-station receiver → dashboard + received-telemetry log                          GROUND STATION
```

## 2. Rates

| Stream | Rate | Notes |
|---|---|---|
| Flight-computer tick | 100 Hz | = IMU rate |
| IMU | 100 Hz | requirement ≥ 100 Hz to SD (engineering package §8) |
| Barometer | 50 Hz | ≥ 20 Hz needed for apogee timing |
| Separation breakwire | 50 Hz | logging only |
| GNSS | 1 Hz | minimum; more if the selected module allows |
| Temperature, battery | 1 Hz | slow quantities |
| Log frames | 50 Hz (example) / ≥ 100 Hz (hardware target) | example decimated to keep the repository small |
| Telemetry packets | 5 Hz | package concept: 2–5 Hz summaries; full-rate data stay on the SD card |

## 3. Freshness rule (what an empty cell means)

A log frame contains the samples taken since the previous frame. Slow sensors therefore appear only in about one
frame per second; in other frames their cells are empty. An empty cell also appears when a value was rejected by
validation (then `quality_flags` has the sensor's bit set) or when the sensor delivered nothing (dropout).
Telemetry is different: it always carries the latest valid value, because the ground display needs a current reading;
since Phase 5 the packet also carries per-sensor health bits, so a value from a sensor that has gone silent is marked stale.

## 4. Validation and error handling at each stage

| Stage | Check | Action |
|---|---|---|
| Acquisition | sensor returns nothing | no sample; frame cell stays empty |
| Processing | NaN / inf / unparseable / outside the plausibility range (Phase 5: schema check before processing) | never reaches the estimator, classifier or telemetry; counted; sensor health drops after 3 nominal periods without a valid sample |
| Logger | required field missing / invalid, time duplicate or backwards | frame rejected and counted |
| Logger | optional value non-finite, unparseable or outside the plausibility range | written empty, sensor bit set in `quality_flags`, counted |
| Logger | time gap > 3 nominal periods | frame kept, bit 6 set |
| Telemetry | value outside the packet range | saturates at the limit (never wraps) |
| Receiver | wrong length / sync / version / CRC | packet rejected and counted |
| Receiver | sequence gap / repeat | counted as missing / duplicate (16-bit wrap aware) |
| Reader (analysis) | wrong column count, CRC mismatch, required field, time order | row dropped, reported by reason |

## 5. Data-source labelling

| Where | Label |
|---|---|
| Log row | `data_source` = SIMULATED or HARDWARE |
| Log metadata sidecar (`*.meta.json`) | `data_source`, title "NOT FLIGHT DATA", truth profile, seeds |
| Telemetry packet | flags bit 0 = SIMULATED (bits 3–7 = sensor health, packet v2) |
| Ground station | banner "SIMULATED TELEMETRY: not flight data" |
| Analysis plots and report | subtitle / banner "SIMULATED DATA (not flight data)" |

## 6. Example data in this repository

| File | Content |
|---|---|
| `avionics/data/example/example_flight_simulated.csv` | 4547 frames at 50 Hz: 10 s on the pad, then a replay of the existing 1-DOF trajectory (PLACEHOLDER propulsion) |
| `avionics/data/example/example_flight_simulated.meta.json` | Counts, detected events, truth events, assumptions |
| `avionics/data/example/example_flight_simulated_telemetry_capture.csv` | Received packets (hex) after a simulated link with 2 % loss and 1 % corrupted packets |
| `avionics/analysis/results/example_flight_simulated/` | Plots, `flight_summary.json` and `flight_report.md` from the analysis tool |

Regenerate with `python -m avionics.firmware.simulate_flight` and
`python avionics/analysis/flight_data_analysis.py avionics/data/example/example_flight_simulated.csv`.

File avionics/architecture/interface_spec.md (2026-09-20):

# ASTRA-66 avionics: interface specification

> Draft. No avionics component has been selected: every hardware item below is **COMPONENT TO BE SELECTED**. Ranges
> and rates are **requirements** (class C assumptions), not manufacturer specifications. Where a requirement is derived
> from the simulation it uses the PLACEHOLDER propulsion input and must be re-derived with the certified motor's data.
> The candidate classes repeat `avionics/electronics.csv`; their datasheets have not been checked. Nothing here has
> been built or tested, and ASTRA-66 is NOT flight certified.

## 1. Sensor interfaces

The same content is held in code in `avionics/firmware/sensor_interfaces/catalog.py` (tested against the schema).

### 1.1 Inertial measurement unit (IMU)
| Item | Specification |
|---|---|
| Component | COMPONENT TO BE SELECTED (candidate class: 6-axis ±32 g breakout) |
| Measurement | Specific force (3 axes) and angular rate (3 axes), body frame, +z toward the nose |
| Schema fields / unit | `imu_accel_x`, `imu_accel_y`, `imu_accel_z` m/s² · `gyro_x`, `gyro_y`, `gyro_z` deg/s |
| Required range | accel ≥ ±16 g (2× the 7.4 g PLACEHOLDER peak); gyro ≥ ±1000 deg/s (roll not simulated: assumption) |
| Sampling rate | 100 Hz (≥ 100 Hz to SD) |
| Interface | I²C or SPI (SPI preferred for rate) |
| Purpose | Liftoff / burnout detection, acceleration record, estimator input |
| Failure considerations | saturation; temperature bias; vibration aliasing; mounting misalignment; bus lock-up (stale data); unknown orientation under the parachute (handled: estimator goes barometer-only after apogee) |
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

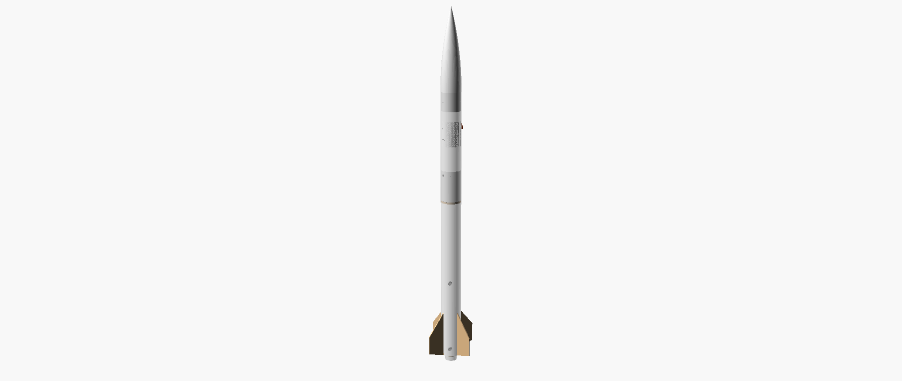
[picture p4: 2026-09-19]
images/astra66_vertical.png

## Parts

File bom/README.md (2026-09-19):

# bom/

Generated by `python build.py` from `documentation/generator/data_tables.py`. Do not edit the CSVs by hand.

| File | Content |
|---|---|
| `bom.csv` | Every part: part no., qty, material, method, dimensions, tolerance, interface, assembly, make/buy, cost range, build level |
| `fasteners.csv` | Metric fasteners and heat-set inserts with standard and location |
| `materials.csv` | Stock materials, quantities and cost ranges |

Costs are USD planning ranges (ASSUMPTION). Motors, tools and shipping are excluded.
Parts marked EXTERNAL (motor, igniter) are never fabricated.

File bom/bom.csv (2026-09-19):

part_no | name | module | qty | material | method | dimensions | tolerance | interface | assembly | make_buy | cost_usd_low | cost_usd_high | in_low_cost_build | purpose
NC-101 | Nose tip section | 100 | 1 | PETG (ASA if painted dark) | FDM print standing on the spigot, tip up, 0.2 mm layers, 3 perimeters, 0 % infill | Tangent ogive sta 0–150, wall 1.2, solid tip 8; 2 mm split web + spigot 10 × 1.6 wall | OD ±0.3; spigot fit tune on coupon | Spigot into NC-102 socket, 0.2 diametral (I-00) | 30-min epoxy, align seam, tape jig | MAKE | 2 | 4 | True | Aerodynamic nose, low drag at M<0.3
NC-102 | Nose base + shoulder | 100 | 1 | PETG | FDM print split face down; chamfered lugs/bosses need no support; 4 perimeters in shoulder | Ogive sta 150–264 + spigot socket; shoulder ⌀63.7 × 60, wall 1.6; 3 radial M3 insert bosses @ [90, 210, 330]°; 3 lugs sta 306–318 @ [30, 150, 270]° | Shoulder ⌀63.7 +0/−0.15 | I-01: 3× M3 radial into PL-201 @ sta 294 | Heat-set inserts, then bond NC-101 | MAKE | 3 | 5 | True | Nose-to-payload interface
NC-103 | Nose bulkhead / ballast mount | 100 | 1 | PETG | FDM print flat, 60 % gyroid | ⌀60.3 × 6, ⌀6.5 centre, 3× ⌀3.4 @ R27.2 | Holes +0.2/−0 | 3× M3 × 10 into NC-102 lug inserts | Bolt; rod nut on aft face | MAKE | 0.5 | 1 | True | Closes payload bay forward; carries ballast
NC-104 | Ballast rod kit | 100 | 1 | A2 stainless M6 rod, nylock nuts, M6 fender washers | Cut rod to 86 mm, deburr | M6 × 86 | Length ±1 | Through NC-103 | Stack washers as needed to hit target CG; nylock both ends | BUY | 3 | 5 | True | Adjustable stability trim
PL-201 | Payload tube | 200 | 1 | 66 mm-class kraft/phenolic body tube | Cut from stock with tube-cutting jig | ⌀66/⌀64 × 250; 3× ⌀3.4 @ sta 294; ⌀14 lens hole @ sta 360/270°; 25 × 40 hatch cut-out @ sta 395/90° | Length ±0.5; end squareness ≤0.5 | I-01 nose, I-02 AV coupler bond | Mark holes with printed wrap-around drill guide | MAKE | 6 | 10 | True | Houses payload bay
PL-202 | GPS / sensor tray + bracket | 200 | 1 | PETG | FDM print | 50 × 82 × 2.5 plate + 22 × 26 × 8 foot (90 overall); 2 M3 inserts @ (±7, -14); 6 M2.5 insert bosses | — | 2× M3 × 16 from inside the AV bay through AV-303 into the foot inserts | Modules on M2.5 standoffs | MAKE | 0.5 | 1 | False | GPS + optional sensor mount
PL-203 | Camera cradle | 200 | 1 | PETG | FDM print | Pocket CAM_W × CAM_H × CAM_LEN (USER: measure camera); saddle R31.9 | Pocket +0.3/+0.1 | Bonded to tube wall, lens concentric with hole | Dry-fit camera, epoxy saddle | MAKE | 0.5 | 1 | False | Holds onboard camera
PL-204 | Lens cowl | 200 | 1 | ASA or PETG | FDM print | 40 long × 20 wide × 8 high teardrop, 15° aft-looking window | Saddle R33 ±0.2 | Bonded over lens hole | Epoxy + fillet; sand fair | MAKE | 0.3 | 0.5 | False | Streamlines lens, protects on landing
PL-205 | Access hatch | 200 | 1 | PETG | FDM print curved panel (0.25 mm nozzle recommended: 1 mm wall) | 39.4 × 24.4 on R33, 2× ⌀2.9 @ ±17 | Edge gap 0.3 ±0.15 | 2× M2.5 × 6 button head into PL-206 ledge inserts | Remove to reach camera button / GPS USB | MAKE | 0.3 | 0.5 | False | Service without removing nose
PL-206 | Hatch doubler frame | 200 | 1 | PETG | FDM print | 54 × 40 saddle R31.9, 2 thick; opening 28 × 25 (6 mm ledges); 2 M2.5 insert bosses | — | Bonded inside tube around cut-out | Epoxy before cutting final opening | MAKE | 0.3 | 0.5 | False | Restores tube stiffness at cut-out; carries the hatch
AV-301 | Avionics coupler | 300 | 1 | Commercial kraft/phenolic coupler | Cut from stock | ⌀63.8/⌀61 × 170 | Slip fit in BODY_ID: 0.1–0.4 diametral | I-02 bond (fwd 70), I-03 slip fit (aft 70) | Bond fwd half into PL-201; aft half sanded / taped to tune separation force | BUY | 5 | 8 | True | Avionics bay structure + separation joint
AV-302 | Switch band | 300 | 1 | Body tube offcut | Cut from stock | ⌀66 × 30; ⌀8 switch access @90°; 4× ⌀2 static ports @45° | Length ±0.3 | Bonded centred on AV-301 | Bond with coupler inserted in both tubes (alignment) | MAKE | 0 | 0 | True | Exterior band, switch and static-port access
AV-303 | Forward bulkhead | 300 | 1 | 6 mm birch ply ×2, laminated | Laser cut or hole saw + disc-sander jig | ⌀60.8 + ⌀63.8 discs; 2× M4 tee-nut ⌀5.5 @±20 (flange fwd); ⌀8 harness @ y+14; 2× ⌀3.4 @ (±7, -14) | Rod holes ±0.2 true position | I-02; bears on coupler fwd end face | Epoxy into coupler; seal with fillet | MAKE | 1 | 2 | True | Rod anchor + payload/av separation
AV-304 | Aft bulkhead | 300 | 1 | 6 mm birch ply ×2, laminated | Laser cut or hole saw | As AV-303; 2× ⌀4.5; ⌀6.5 eyebolt | Rod holes ±0.2 true position | I-04a recovery attachment; outer disc seats on AV-309 | Slides on rods; washer + nylock nut each rod | MAKE | 1 | 2 | True | Removable service closure; shock-cord anchor
AV-305 | Threaded rods | 300 | 2 | M4 A2-70 stainless | Cut, deburr, chamfer | M4 × 190 | ±1 | AV-303 inserts ↔ AV-304 nuts | Loctite 243 into inserts (metal-metal only) | BUY | 3 | 5 | True | Clamp bay; carry recovery load to AV-303
AV-306 | Electronics sled | 300 | 1 | PETG | FDM print flat, 100 % around sleeves | 52 × 3 × 140, 2 rod sleeves ⌀7.5/⌀4.4, 10 M2.5 insert bosses (25 mm pitch), switch tower 20 high, 2 M3 cage inserts, zip slots | Sleeve pitch 40 ±0.2 | Rides on AV-305 | Modules on M2.5 nylon standoffs | MAKE | 1 | 2 | True | Modular electronics carrier
AV-307 | Arming switch | 300 | 1 | COTS latching switch (screw or key type) | Purchase | Per maker; actuator reachable through ⌀8 | — | Wired battery → regulator | Mount to sled bracket aligned with band hole | BUY | 3 | 8 | True | Power electronics on the pad only
AV-308 | Battery cage + strap | 300 | 1 | PETG + hook-and-loop / aramid strap | Print | Open-bottom cage for 55 × 28 × 9 cell (USER; width ≤ 28.8) | — | Sled underside, 2× M3 × 16 into AV-306 inserts | Screw from below; strap through side slots | MAKE | 1 | 2 | True | Positive battery retention under load
AV-309 | Aft bulkhead face gasket | 300 | 1 | 1.5 mm EVA / neoprene foam | Knife/die cut from DXF | Annulus ⌀63.8 / ⌀61, 1.5 free (0.5 compressed) | — | Coupler aft end face ↔ AV-304 outer disc | Contact adhesive to AV-304 outer disc | MAKE | 1 | 2 | True | Keeps ejection gas out of the bay
AV-312 | Rod spacers | 300 | 4 | PETG | FDM print upright | ⌀7.5 / ⌀4.4; 2 × 7 fwd, 2 × 11.5 aft | Length ±0.1 | On AV-305 between bulkheads and sled | Fwd pair, sled, aft pair, then AV-304 + nuts | MAKE | 0.2 | 0.5 | True | Clamps the sled axially
AV-311 | Forged eyebolt M6 | 300 | 1 | Forged steel, zinc or stainless | Purchase | M6 shank; RATED working load from maker | — | I-04a | Nut + fender washer inside; threadlock | BUY | 3 | 6 | True | Recovery attachment point
BO-401 | Booster tube | 400 | 1 | 66 mm-class kraft/phenolic body tube | Cut; slot with router jig or fine saw + file | ⌀66/⌀64 × 600; 4 slots 3.3 × 140 from the tab front, open aft; 2× ⌀4.5 rail-button holes @45° | Slot width +0.2/−0; slots 90° ±0.5° | I-03, I-06, I-07 | Mark slots with printed wrap guide | MAKE | 12 | 20 | True | Recovery bay + fin can shell
BO-402 | Motor mount tube | 400 | 1 | 29 mm-class kraft/phenolic MMT | Cut from stock | ⌀31 OD; ID + length PER MOTOR/RETAINER MAKER (placeholder 260) | Axis parallel to body ≤0.3° | I-05 (COTS retainer) | Rings bonded while clamped in alignment jig | BUY | 4 | 7 | True | Holds certified motor; transmits thrust
BO-403 | Fin-can core | 400 | 1 | ASA (heat tolerance) — PETG only for ground demo | FDM print aft-end down, rails 100 %, rings 70 % | ⌀63.7 × 142; bore ⌀31.3; 8 rails 1.6 thick; guide 3.2; tab floors to R20; 4× M3 inserts @R26; rail boss @45° | Guide width ±0.1; angular 90° ±0.3° | I-06 fins; bonded to MMT + tube | Bond to MMT, then slide into tube with fins as alignment keys | MAKE | 3 | 5 | True | Locates and supports removable fins
BO-404 | Forward centering ring | 400 | 1 | 6 mm birch ply | Laser cut / hole saw | ⌀63.7 / ⌀31.3 × 6; 6 × 3 aramid notch @225° | OD +0/−0.2 | I-04b recovery load path | Bond + fillets both faces | MAKE | 1 | 2 | True | Centres MMT; shock-cord anchor ring
BO-405 | Aft fin lock ring | 400 | 1 | 6 mm birch ply (sealed) | Laser cut | ⌀63.7 / ⌀40 [RET_CLEAR_D] × 6; 4× ⌀3.4 @R26 | Bore per retainer +1 | 4× M3 × 12 into BO-403 | Removable: unscrew to slide fins out aft | MAKE | 0.5 | 1 | True | Axially locks fins
BO-406 | Fins | 400 | 4 | 3 mm aircraft birch ply (baseline) / 3.2 mm G10 (upgrade) | Laser cut or scroll saw from 1:1 template; edges radiused | Root 150, tip 60, span 60, sweep 70; tab 134 × 12.8 | Profile ±0.3; cant 0° ±0.25° | I-06 | Slide in from aft, lock with BO-405; no glue | MAKE | 6 | 12 | True | Stability; replaceable after damage
BO-407 | Motor retainer | 400 | 1 | COTS 29 mm screw-on retainer (metal) | PURCHASE — never fabricate | All dimensions from manufacturer drawing | Per manufacturer | I-05 | Bond to MMT exactly per maker's instructions; mentor inspection | BUY | 20 | 35 | True | Positive motor retention
BO-408 | Rail buttons | 400 | 2 | COTS 1010-size rail buttons + screws | Purchase | Per maker; must match RANGE rail | In line ±0.5 over 230 mm | I-07 | Fwd into BO-409 insert, aft into BO-403 boss | BUY | 4 | 8 | True | Launch guidance
BO-409 | Forward rail-button boss | 400 | 1 | PETG | FDM print | 20 × 16 × 8 saddle, insert per button screw | — | Bonded to tube + BO-404 fwd face | Epoxy; install insert before bonding | MAKE | 0.2 | 0.5 | True | Hard-point for rail button
BO-410 | Aramid anchor leader | 400 | 1 | COTS flame-resistant aramid cord, rated | Purchase; cut 1.5 m | Rated breaking strength ≥ design (see loads) | — | I-04b | Wrap MMT between BO-404 and BO-403, bond with epoxy, exit through notch | BUY | 6 | 10 | True | Heat-proof recovery anchor
RC-501 | Parachute | 500 | 1 | Ripstop nylon | PURCHASE | Nominal ⌀≈1067 (42 in class) | — | Quick link to shock cord loop at 1/3 from AV end | Z-fold per maker; lines untangled | BUY | 25 | 45 | True | Descent ≈ 5 m/s
RC-502 | Parachute protector | 500 | 1 | Flame-resistant fabric (e.g. Nomex-type) | PURCHASE | Size per maker for chute + 64 mm tube | — | Between chute and motor ejection gas | Burrito wrap | BUY | 10 | 18 | True | Protects chute from ejection heat
RC-503 | Shock cord | 500 | 1 | Tubular nylon, rated | PURCHASE | 4 m, sewn end loops | — | AV-311 ↔ BO-410 via RC-504 | Accordion fold, masking-tape bundles | BUY | 8 | 15 | True | Energy absorption, keeps parts tethered
RC-504 | Quick links | 500 | 3 | Steel, marked working load | PURCHASE | 4–5 mm; rated WLL ≥ design | — | Recovery train | Screw gate closed, check | BUY | 4 | 8 | True | Serviceable connections
RC-505 | Swivel | 500 | 1 | Ball-bearing swivel, rated | PURCHASE | Rated ≥ design | — | Chute riser | Between chute and cord | BUY | 3 | 6 | False | Prevents line twist
MT-601 | Certified motor | 600 | 1 | EXTERNAL — certified commercial product | Purchased by / through a certified mentor or club; not designed, modified or stored by students unless the law and the club allow | From certification data | — | I-05 | Prepared & installed per maker instructions under mentor/RSO supervision | EXT | 0 | 0 | True | Propulsion + ejection
MT-602 | Igniter | 600 | 1 | EXTERNAL — supplied / approved by maker, handled by range | Not fabricated | — | — | Range launch controller | Installed at the pad only, per range procedure | EXT | 0 | 0 | True | Ignition
GS-701 | Fin alignment jig | 700 | 1 | PETG | FDM print | Collar ⌀82 × 30, 4 slots FIN_T+0.3 | Slots 90° ±0.2° | Over booster tail | Use during core bonding | MAKE | 1 | 2 | True | Guarantees fin spacing & zero cant
GS-702 | CG balance cradle | 700 | 1 | Ply offcuts + printed V-blocks | Cut / print | Knife-edge on 300 mm base | — | Supports airframe | Balance fully loaded rocket, mark CG | MAKE | 1 | 3 | True | Measure CG
GS-703 | Bench harness | 700 | 1 | JST-XH/GH leads, USB extension | Crimp | — | — | I-08 connectors | — | MAKE | 4 | 8 | True | Ground test without airframe
GS-704 | Rail fit gauge | 700 | 1 | 300 mm offcut of 1010 rail (or range-lent) | Purchase / borrow | — | — | I-07 | Slide test, no binding | BUY | 0 | 8 | False | Verify button alignment
GS-705 | Display / transport stand | 700 | 1 | 12 mm ply | Cut | 2 cradles, 600 apart | — | — | — | MAKE | 3 | 6 | False | Exhibition + safe transport

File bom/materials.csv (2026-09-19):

material | quantity | parts | note | cost_usd_low | cost_usd_high
Kraft or phenolic body tube, 66 mm class | 2 lengths (≥ 900 mm total) | PL-201, AV-302, BO-401 | Measure OD/ID; buy a matching coupler from the same supplier | 20 | 35
Matching coupler tube | ≥ 200 mm | AV-301 | Same supplier/series as body tube | 5 | 8
29 mm-class motor mount tube | ≥ 300 mm | BO-402 | Confirm fit with motor maker's casing dimensions | 4 | 7
Aircraft birch plywood 3 mm (3-ply) | 300 × 300 | BO-406 | Aviation grade; flat, void-free | 8 | 14
Birch plywood 6 mm | 300 × 300 | AV-303/304, BO-404/405 | Laser-cut service or hole saw | 6 | 10
PETG filament | ≈ 0.35 kg | Nose, payload parts, sled, jigs | Dry before printing | 8 | 12
ASA filament | ≈ 0.1 kg | BO-403, PL-204 | Print enclosed; ventilate | 4 | 8
Epoxy, 30-min structural + laminating | 2 kits | All bonds, fillets, fin edge sealing | Measure by weight; record batch | 15 | 25
Primer, filler, paint, sandpaper | — | Finish | Light coats — paint is mass aft | 15 | 30
Foam, tape, grommets, zip ties | — | Gasket, fit tuning, harness | — | 5 | 8

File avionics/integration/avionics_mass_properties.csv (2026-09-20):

component | mass_g | source | location | confidence | cg_shift_if_removed_mm | cg_shift_per_10g_mm | sm_change_per_10g_cal
PL-202 GPS / sensor tray + bracket | 18.9 | CALCULATED (CAD: PL-202 V=14.86 cm3 x 1.27 x fill 1.0) | STA 402.4 mm, 200 Payload | MEDIUM: CAD volume x assumed density | 4.66 | -2.41 | 0.036
PL-203 Camera cradle | 11.7 | CALCULATED (CAD: PL-203 V=10.24 cm3 x 1.27 x fill 0.9) | STA 366.2 mm, 200 Payload | MEDIUM: CAD volume x assumed density | 3.22 | -2.71 | 0.041
PL-204 Lens cowl | 1.7 | CALCULATED (CAD: PL-204 V=2.70 cm3 x 1.07 x fill 0.6) | STA 376.2 mm, 200 Payload | MEDIUM: CAD volume x assumed density | 0.45 | -2.62 | 0.04
EL-GPS GPS module + patch antenna | 20.0 | ASSUMPTION (weigh) | STA 378.0 mm, 200 Payload | LOW: estimate, weigh | 5.35 | -2.61 | 0.04
EL-CAM Mini camera (user-selected) | 35.0 | USER-SUPPLIED (weigh) | STA 360.0 mm, 200 Payload | LOW: placeholder, weigh | 10.02 | -2.76 | 0.042
AV-305 2x M4x190 A2 rods, nuts, washers | 32.4 | CALCULATED | STA 534.0 mm, 300 Avionics | MEDIUM: calculated | 4.47 | -1.33 | 0.02
AV-306 Electronics sled | 32.1 | CALCULATED (CAD: AV-306 V=28.12 cm3 x 1.27 x fill 0.9) | STA 527.1 mm, 300 Avionics | MEDIUM: CAD volume x assumed density | 4.61 | -1.39 | 0.021
EL-AV Avionics set: MCU, IMU, baro, SD, radio, buzzer, wiring | 59.0 | ASSUMPTION (sum of module estimates -- weigh) | STA 527.0 mm, 300 Avionics | LOW: estimate, weigh | 8.68 | -1.39 | 0.021
EL-BAT 1S LiPo battery + strap | 27.0 | ASSUMPTION (weigh (rev B: cage split out)) | STA 492.8 mm, 300 Avionics | LOW: estimate, weigh | 4.64 | -1.67 | 0.025
AV-308 Battery cage | 11.5 | CALCULATED (CAD: AV-308 V=9.04 cm3 x 1.27 x fill 1.0) | STA 492.8 mm, 300 Avionics | MEDIUM: CAD volume x assumed density | 1.95 | -1.67 | 0.025
AV-312 Rod spacers (2 fwd + 2 aft) | 1.4 | CALCULATED (CAD: AV-312 V=1.07 cm3 x 1.27 x fill 1.0) | STA 546.3 mm, 300 Avionics | MEDIUM: CAD volume x assumed density | 0.17 | -1.23 | 0.019
AV-309/310 Gasket, switch, adhesive allowance | 12.0 | ASSUMPTION | STA 529.0 mm, 300 Avionics | LOW: estimate, weigh | 1.68 | -1.37 | 0.021

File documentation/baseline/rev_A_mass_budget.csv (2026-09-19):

id | item | module | mass_g | cg_station_mm | provenance | note
NC-101 | Nose tip section (ogive 0-150, spigot) | 100 Nose | 25.4 | 96.8 | CALCULATED | PETG shell, area x wall
NC-102 | Nose base + shoulder | 100 Nose | 61.7 | 247.2 | CALCULATED | incl. 4 g bosses (ASM)
NC-103 | Nose bulkhead / ballast mount | 100 Nose | 13.1 | 321.0 | CALCULATED | 60 % effective infill (ASM)
NC-104 | Ballast rod M6x80 + 2 nylock + 2 washers | 100 Nose | 19.9 | 284.0 | CALCULATED | no ballast washers in baseline
NC-105 | Nose fasteners (6x M3 insert, 6x M3 screw) | 100 Nose | 8.0 | 294.0 | ASSUMPTION
PL-201 | Payload tube | 200 Payload | 51.1 | 389.0 | CALCULATED
PL-202 | GPS / sensor tray + bracket | 200 Payload | 15.0 | 393.0 | ASSUMPTION
PL-203 | Camera cradle | 200 Payload | 10.0 | 360.0 | ASSUMPTION
PL-204 | Lens cowl | 200 Payload | 4.0 | 360.0 | ASSUMPTION
PL-205/206 | Access hatch + doubler frame | 200 Payload | 8.0 | 395.0 | ASSUMPTION
EL-GPS | GPS module + patch antenna | 200 Payload | 20.0 | 378.0 | ASSUMPTION | weigh
EL-CAM | Mini camera (user-selected) | 200 Payload | 35.0 | 360.0 | USER-SUPPLIED | weigh
AV-301 | Coupler tube | 300 Avionics | 46.7 | 529.0 | CALCULATED
AV-302 | Switch band | 300 Avionics | 6.1 | 529.0 | CALCULATED
AV-303 | Forward bulkhead (2-ply laminate) + 2 M4 inserts | 300 Avionics | 28.9 | 444.0 | CALCULATED
AV-304 | Aft bulkhead (2-ply laminate) | 300 Avionics | 24.9 | 614.0 | CALCULATED
AV-311 | M6 forged eyebolt + nut + washers | 300 Avionics | 25.0 | 638.0 | ASSUMPTION | weigh
AV-305 | 2x M4x190 A2 rods, nuts, washers | 300 Avionics | 32.4 | 534.0 | CALCULATED
AV-306 | Electronics sled | 300 Avionics | 25.0 | 527.0 | ASSUMPTION
EL-AV | Avionics set: MCU, IMU, baro, SD, radio, buzzer, wiring | 300 Avionics | 59.0 | 527.0 | ASSUMPTION | sum of module estimates -- weigh
EL-BAT | 1S LiPo battery + cage + strap | 300 Avionics | 33.0 | 502.0 | ASSUMPTION | weigh
AV-309/310 | Gasket, switch, adhesive allowance | 300 Avionics | 12.0 | 529.0 | ASSUMPTION
BO-401 | Booster tube (slotted) | 400 Booster | 121.9 | 844.0 | CALCULATED | minus fin slots
BO-402 | Motor mount tube | 400 Booster | 24.5 | 1024.0 | CALCULATED
BO-404 | Forward centering ring | 400 Booster | 9.9 | 897.0 | CALCULATED
BO-403 | Fin-can core (ASA) | 400 Booster | 59.9 | 1067.0 | CALCULATED | rings 70 % infill, rails solid (ASM)
BO-405 | Aft fin lock ring | 400 Booster | 7.9 | 1141.0 | CALCULATED
BO-406 | Fins x4 (3 mm birch ply, finished) | 400 Booster | 77.4 | 1077.4 | CALCULATED
BO-407 | Motor retainer (commercial) | 400 Booster | 25.0 | 1154.0 | COMMERCIAL SPEC | placeholder
BO-408/409 | 2 rail buttons + fwd boss + screws | 400 Booster | 10.0 | 1000.0 | ASSUMPTION
BO-410 | Aramid anchor leader + lock-ring screws | 400 Booster | 14.0 | 934.0 | ASSUMPTION
BO-ADH | Epoxy fillets and bonds (booster) | 400 Booster | 20.0 | 1014.0 | ASSUMPTION
PL-PNT | Primer + paint, forward airframe | 200 Payload | 10.0 | 330 | ASSUMPTION
BO-PNT | Primer + paint, booster | 400 Booster | 15.0 | 844.0 | ASSUMPTION
RC-501 | Parachute (~0.9 m, ripstop) | 500 Recovery | 55.0 | 740.0 | ASSUMPTION | weigh purchased chute
RC-502 | Flame-resistant chute protector | 500 Recovery | 20.0 | 800.0 | ASSUMPTION
RC-503 | Shock cord 4 m | 500 Recovery | 40.0 | 720.0 | ASSUMPTION
RC-504/505 | 3 quick links + swivel | 500 Recovery | 15.0 | 680.0 | ASSUMPTION
MT-601 | Certified motor (EXTERNAL, placeholder mass) | 600 Motor | 110.0 | 1091.5 | COMMERCIAL SPEC | replace with certification data

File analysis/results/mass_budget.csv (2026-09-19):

id | item | module | mass_g | cg_station_mm | provenance | note
NC-101 | Nose tip section (ogive 0-150, spigot) | 100 Nose | 24.9 | 106.4 | CALCULATED | CAD: NC-101 V=19.62 cm3 x 1.27 x fill 1.0
NC-102 | Nose base + shoulder | 100 Nose | 64.1 | 248.1 | CALCULATED | CAD: NC-102 V=50.50 cm3 x 1.27 x fill 1.0
NC-103 | Nose bulkhead / ballast mount | 100 Nose | 12.8 | 321.0 | CALCULATED | CAD: NC-103 V=16.76 cm3 x 1.27 x fill 0.6
NC-104 | Ballast rod M6x86 + 2 nylock + 2 washers | 100 Nose | 20.9 | 287.0 | CALCULATED | no ballast washers in baseline
NC-105 | Nose fasteners (6x M3 insert, 6x M3 screw) | 100 Nose | 8.0 | 294.0 | ASSUMPTION
PL-201 | Payload tube | 200 Payload | 50.0 | 389.0 | CALCULATED | CAD: PL-201 V=50.05 cm3 x 1.0 x fill 1.0
PL-202 | GPS / sensor tray + bracket | 200 Payload | 18.9 | 402.4 | CALCULATED | CAD: PL-202 V=14.86 cm3 x 1.27 x fill 1.0
PL-203 | Camera cradle | 200 Payload | 11.7 | 366.2 | CALCULATED | CAD: PL-203 V=10.24 cm3 x 1.27 x fill 0.9
PL-204 | Lens cowl | 200 Payload | 1.7 | 376.2 | CALCULATED | CAD: PL-204 V=2.70 cm3 x 1.07 x fill 0.6
PL-205/206 | Access hatch + doubler frame | 200 Payload | 2.5 | 395.0 | CALCULATED | CAD: PL-205 V=0.76 cm3 x 1.27 x fill 1.0; PL-206 V=1.19 cm3 x 1.27 x fill 1.0
EL-GPS | GPS module + patch antenna | 200 Payload | 20.0 | 378.0 | ASSUMPTION | weigh
EL-CAM | Mini camera (user-selected) | 200 Payload | 35.0 | 360.0 | USER-SUPPLIED | weigh
AV-301 | Coupler tube | 300 Avionics | 46.5 | 529.0 | CALCULATED | CAD: AV-301 V=46.54 cm3 x 1.0 x fill 1.0
AV-302 | Switch band | 300 Avionics | 6.1 | 529.0 | CALCULATED | CAD: AV-302 V=6.06 cm3 x 1.0 x fill 1.0
AV-303 | Forward bulkhead (2-ply laminate) + 2 M4 inserts | 300 Avionics | 27.9 | 443.9 | CALCULATED | CAD: AV-303 V=35.19 cm3 x 0.68 x fill 1.0 +4.0 g tee-nuts (ASM)
AV-304 | Aft bulkhead (2-ply laminate) | 300 Avionics | 24.3 | 614.6 | CALCULATED | CAD: AV-304 V=35.80 cm3 x 0.68 x fill 1.0
AV-311 | M6 forged eyebolt + nut + washers | 300 Avionics | 25.0 | 638.5 | ASSUMPTION | weigh
AV-305 | 2x M4x190 A2 rods, nuts, washers | 300 Avionics | 32.4 | 534.0 | CALCULATED
AV-306 | Electronics sled | 300 Avionics | 32.1 | 527.1 | CALCULATED | CAD: AV-306 V=28.12 cm3 x 1.27 x fill 0.9
EL-AV | Avionics set: MCU, IMU, baro, SD, radio, buzzer, wiring | 300 Avionics | 59.0 | 527.0 | ASSUMPTION | sum of module estimates -- weigh
EL-BAT | 1S LiPo battery + strap | 300 Avionics | 27.0 | 492.8 | ASSUMPTION | weigh (rev B: cage split out)
AV-308 | Battery cage | 300 Avionics | 11.5 | 492.8 | CALCULATED | CAD: AV-308 V=9.04 cm3 x 1.27 x fill 1.0
AV-312 | Rod spacers (2 fwd + 2 aft) | 300 Avionics | 1.4 | 546.3 | CALCULATED | CAD: AV-312 V=1.07 cm3 x 1.27 x fill 1.0
AV-309/310 | Gasket, switch, adhesive allowance | 300 Avionics | 12.0 | 529.0 | ASSUMPTION
BO-401 | Booster tube (slotted) | 400 Booster | 120.6 | 840.4 | CALCULATED | CAD: BO-401 V=120.56 cm3 x 1.0 x fill 1.0
BO-402 | Motor mount tube | 400 Booster | 24.5 | 1024.0 | CALCULATED | CAD: BO-402 V=24.49 cm3 x 1.0 x fill 1.0
BO-404 | Forward centering ring | 400 Booster | 9.8 | 897.0 | CALCULATED | CAD: BO-404 V=14.38 cm3 x 0.68 x fill 1.0
BO-403 | Fin-can core (ASA) | 400 Booster | 66.5 | 1067.5 | CALCULATED | CAD: BO-403 V=73.12 cm3 x 1.07 x fill 0.85
BO-405 | Aft fin lock ring | 400 Booster | 7.7 | 1141.0 | CALCULATED | CAD: BO-405 V=11.36 cm3 x 0.68 x fill 1.0
BO-406 | Fins x4 (3 mm birch ply, finished) | 400 Booster | 71.9 | 1077.8 | CALCULATED | CAD: BO-406 V=24.05 cm3 x 0.68 x fill 1.0 x finish 1.1 x 4
BO-407 | Motor retainer (commercial) | 400 Booster | 25.0 | 1154.0 | COMMERCIAL SPEC | placeholder
BO-408/409 | 2 rail buttons + fwd boss + screws | 400 Booster | 10.0 | 1000.0 | ASSUMPTION
BO-410 | Aramid anchor leader + lock-ring screws | 400 Booster | 14.0 | 934.0 | ASSUMPTION
BO-ADH | Epoxy fillets and bonds (booster) | 400 Booster | 20.0 | 1014.0 | ASSUMPTION
PL-PNT | Primer + paint, forward airframe | 200 Payload | 10.0 | 330 | ASSUMPTION
BO-PNT | Primer + paint, booster | 400 Booster | 15.0 | 844.0 | ASSUMPTION
RC-501 | Parachute (~0.9 m, ripstop) | 500 Recovery | 55.0 | 740.5 | ASSUMPTION | weigh purchased chute
RC-502 | Flame-resistant chute protector | 500 Recovery | 20.0 | 800.5 | ASSUMPTION
RC-503 | Shock cord 4 m | 500 Recovery | 40.0 | 720.5 | ASSUMPTION
RC-504/505 | 3 quick links + swivel | 500 Recovery | 15.0 | 680.5 | ASSUMPTION
MT-601 | Certified motor (EXTERNAL, placeholder mass) | 600 Motor | 110.0 | 1091.5 | COMMERCIAL SPEC | replace with certification data

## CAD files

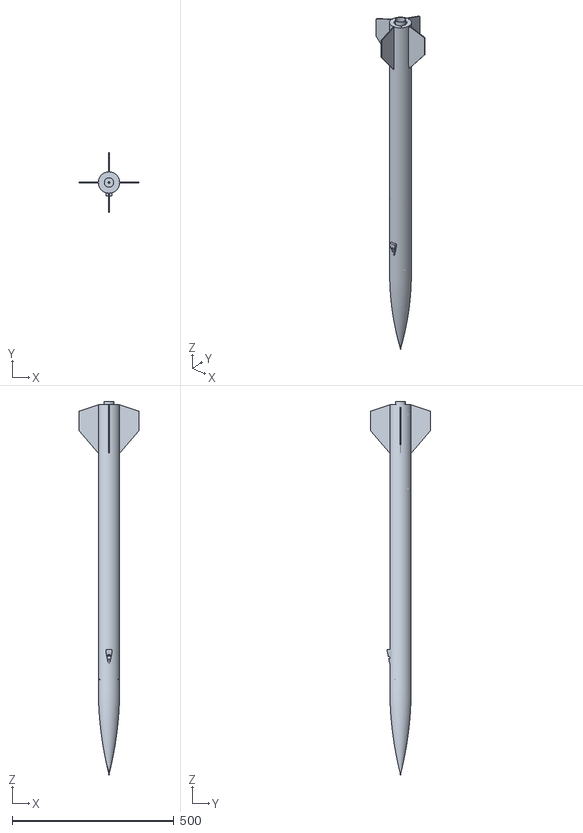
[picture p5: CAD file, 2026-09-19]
cad/exports/assembly/astra66_assembly_flight_parts.stl
186.0 x 186.0 x 1154.0

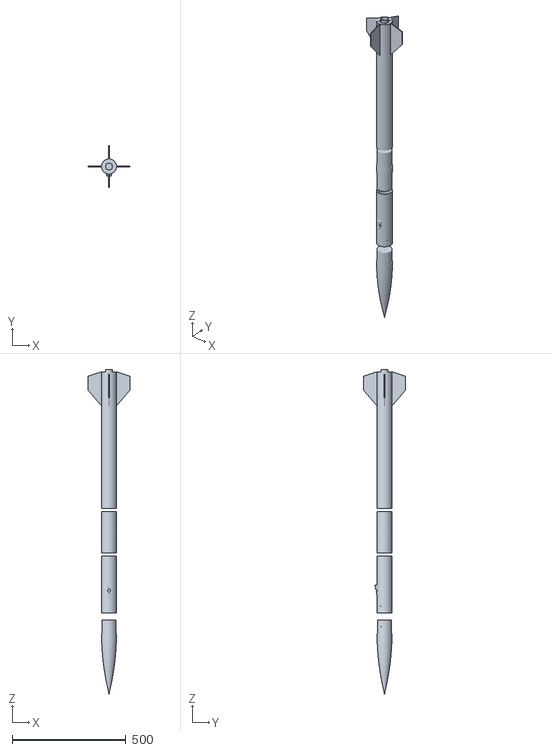
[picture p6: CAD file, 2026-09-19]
cad/exports/assembly/astra66_exploded_flight_parts.stl
186.0 x 186.0 x 1424.0

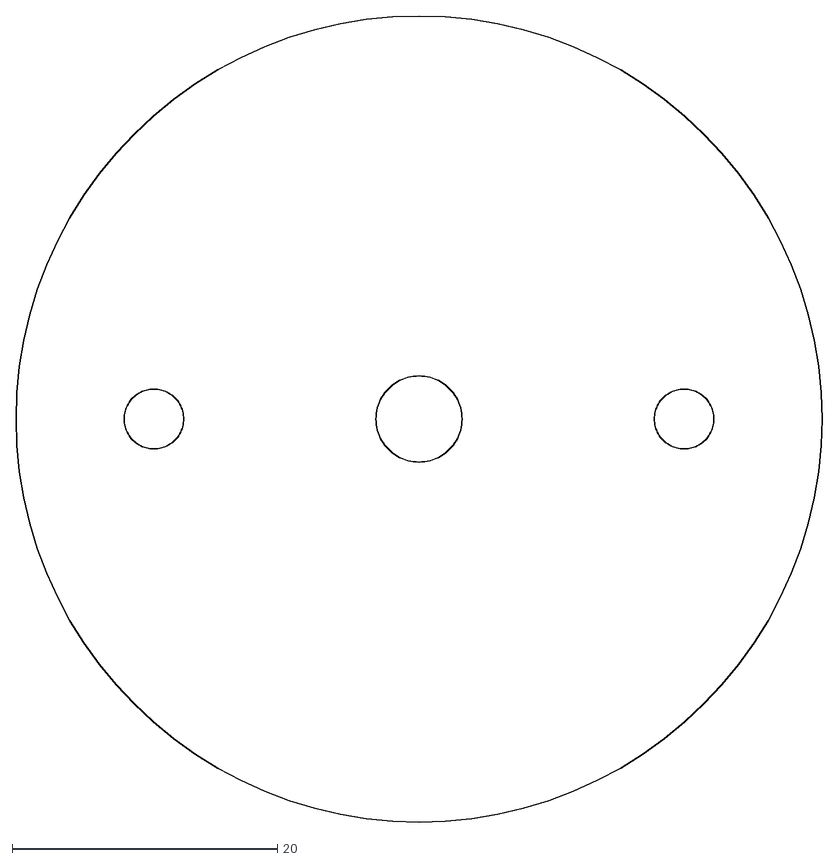
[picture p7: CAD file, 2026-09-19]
cad/exports/dxf/AV-304-inner_aft_bulkhead_2_discs.dxf
60.8 x 60.8

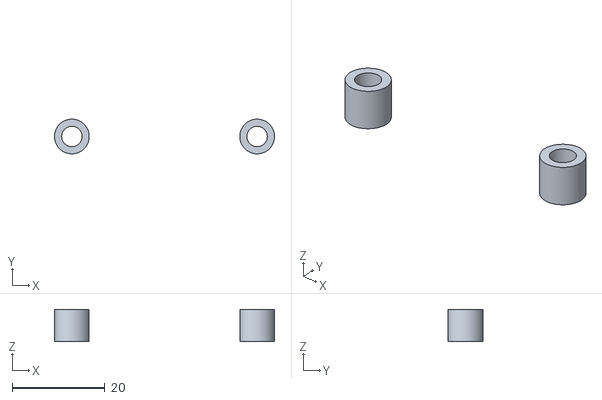
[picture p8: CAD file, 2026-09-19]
cad/exports/stl/AV-312-fwd_rod_spacers_2_fwd_2_aft.stl
47.5 x 7.50 x 7.00

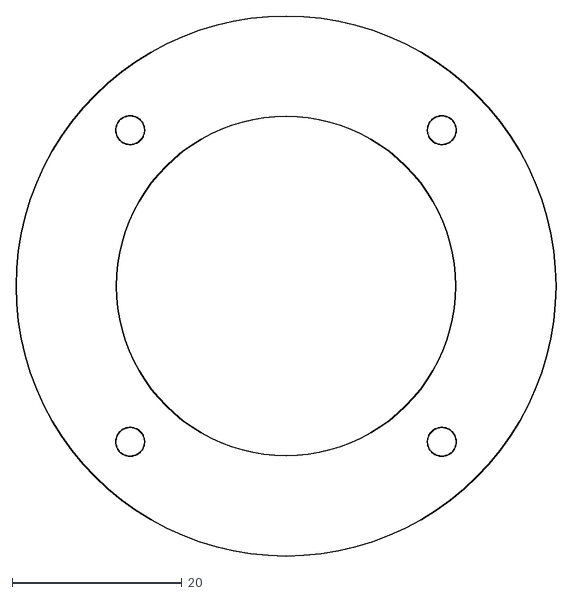
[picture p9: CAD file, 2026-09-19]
cad/exports/dxf/BO-405_aft_fin_lock_ring.dxf
63.7 x 63.7

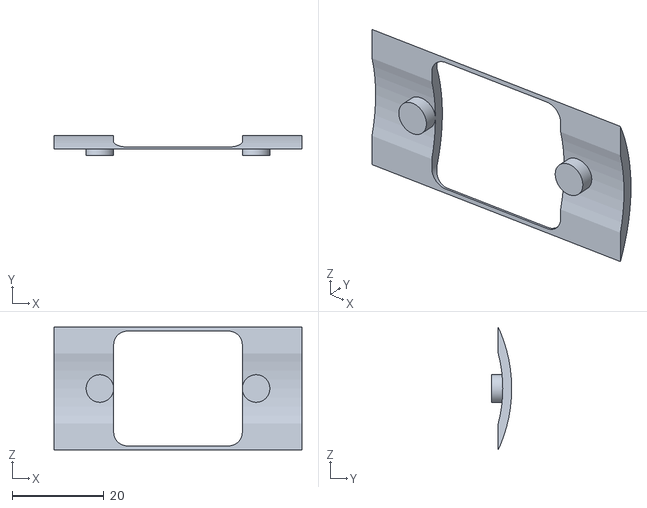
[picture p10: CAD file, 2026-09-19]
cad/exports/stl/PL-206_hatch_doubler_frame.stl
54.0 x 4.45 x 26.7

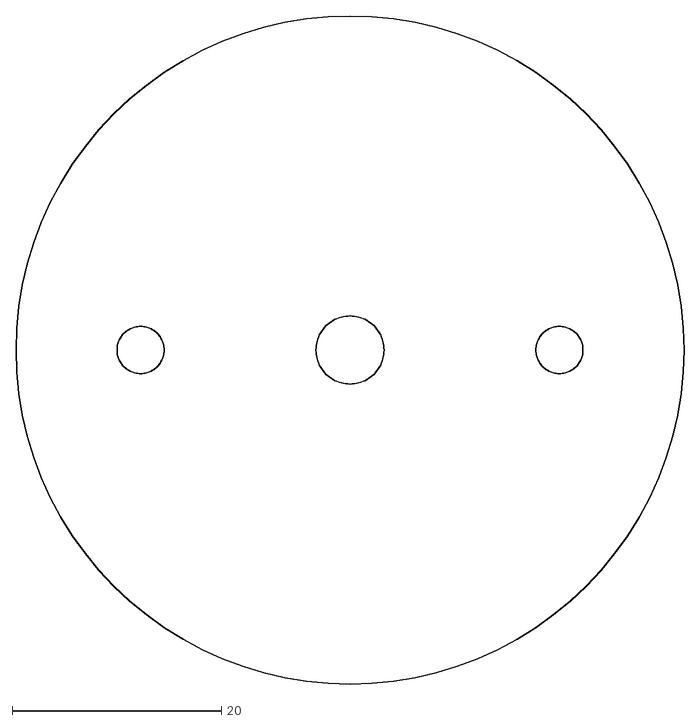
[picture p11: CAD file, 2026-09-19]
cad/exports/dxf/AV-304-outer_aft_bulkhead_2_discs.dxf
63.8 x 63.8

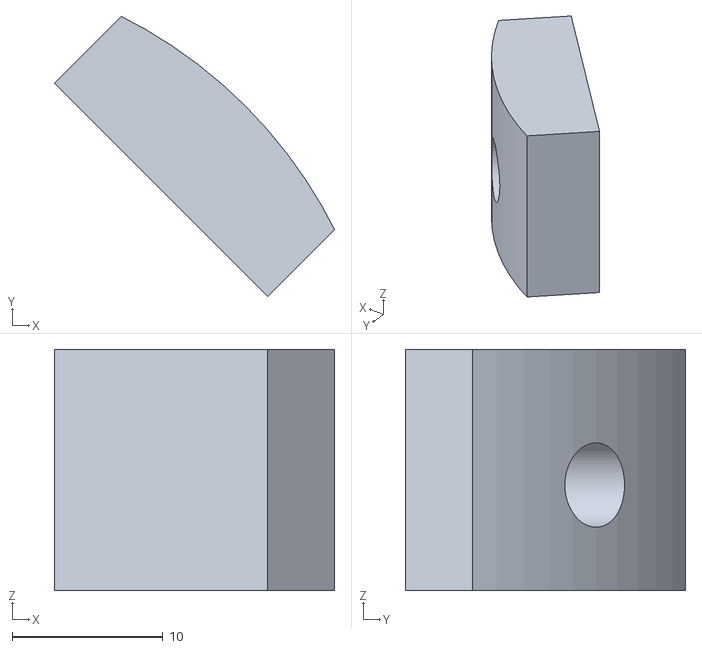
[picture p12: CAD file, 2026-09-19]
cad/exports/stl/BO-409_forward_rail_button_boss.stl
18.6 x 18.6 x 16.0

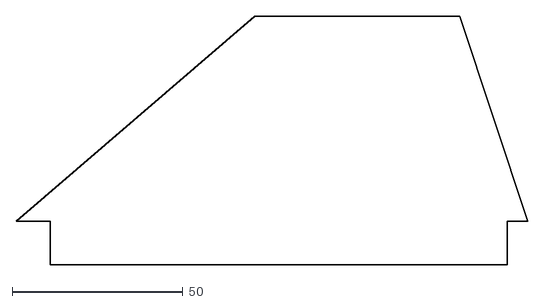
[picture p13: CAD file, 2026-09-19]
cad/exports/dxf/BO-406_fin_x4_1_spare.dxf
150.0 x 72.8

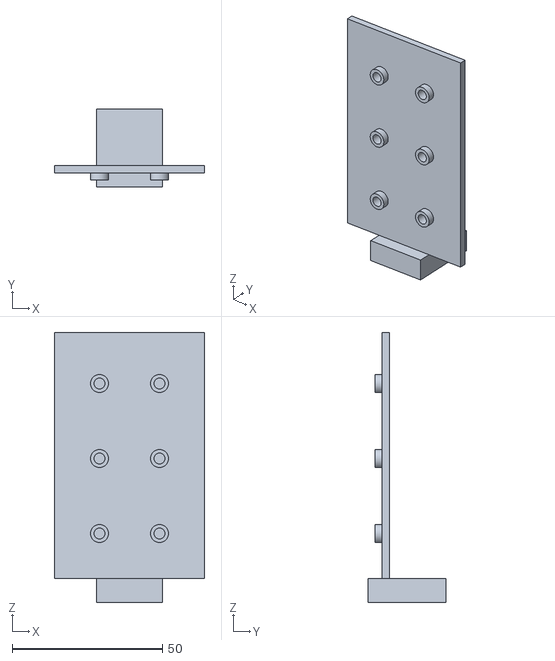
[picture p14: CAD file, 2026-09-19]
cad/exports/stl/PL-202_gps_sensor_tray.stl
50.0 x 26.0 x 90.0

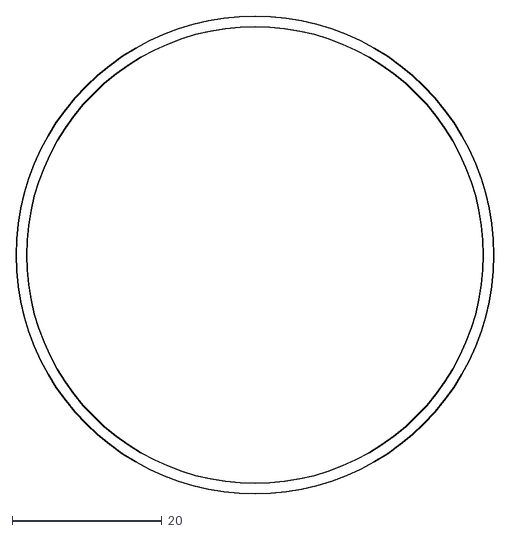
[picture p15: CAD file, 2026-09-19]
cad/exports/dxf/AV-309_aft_bulkhead_face_gasket.dxf
63.8 x 63.8

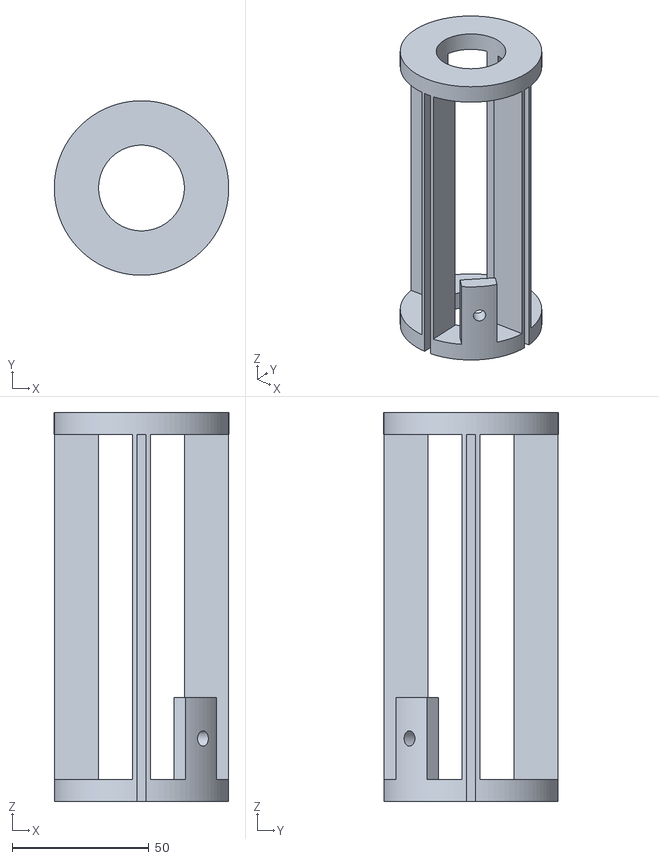
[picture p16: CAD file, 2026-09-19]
cad/exports/stl/BO-403_fin_can_core.stl
63.7 x 63.7 x 142.0

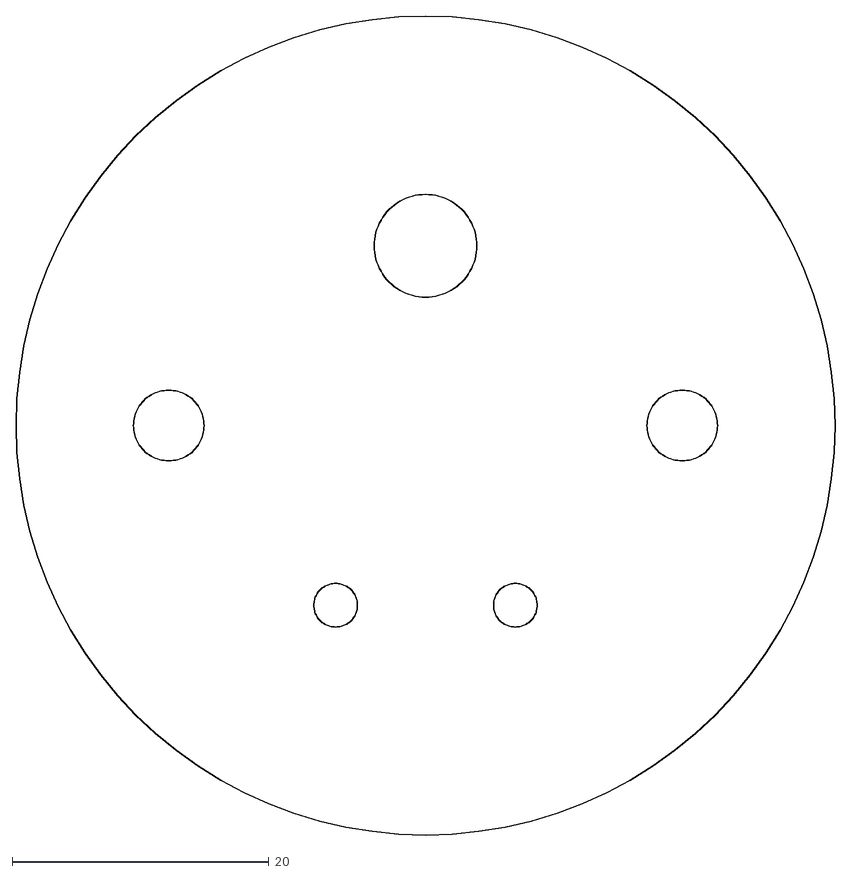
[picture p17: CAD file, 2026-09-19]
cad/exports/dxf/AV-303-outer_forward_bulkhead_2_discs.dxf
63.8 x 63.8

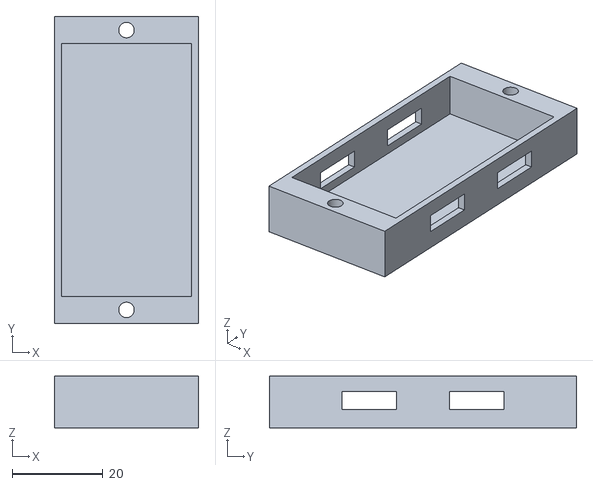
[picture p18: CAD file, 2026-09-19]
cad/exports/stl/AV-308_battery_cage.stl
31.8 x 67.6 x 11.4

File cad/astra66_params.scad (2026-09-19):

// ASTRA-66 parameters -- GENERATED by build.py from analysis.py. Edit analysis.py and rebuild,
// or override here for quick CAD experiments (analysis will then be out of date).

BODY_OD          = 66.0;   // [ASSUMPTION] mm - Nominal 66 mm-class spiral kraft/phenolic body tube. MEASURE the purchased tube and update.
BODY_ID          = 64.0;   // [ASSUMPTION] mm - Measure purchased tube (3 places, 2 axes). Drives every shoulder, ring and bulkhead fit.
CPL_OD           = 63.8;   // [ASSUMPTION] mm - Matching commercial coupler. Must slip-fit BODY_ID (0.1-0.4 mm diametral clearance).
CPL_ID           = 61.0;   // [ASSUMPTION] mm - Measure purchased coupler.
TUBE_RHO         = 1.0;   // [ASSUMPTION] g/cm3 - Effective density of paper/phenolic tube. Verify by weighing a known length.
FIT_SH           = 0.3;   // [ASSUMPTION] mm - Diametral clearance, printed shoulder / ring in tube. Tune with a printed test coupon first.
NC_L             = 264.0;   // [ASSUMPTION] mm - Exposed nose length, tangent ogive, fineness 4.0 (NC_L / BODY_OD).
NC_WALL          = 1.2;   // [ASSUMPTION] mm - Printed ogive wall = 3 perimeters x 0.4 mm nozzle.
NC_SH_L          = 60.0;   // [ASSUMPTION] mm - Shoulder length ~0.9 calibre.
NC_SH_WALL       = 1.6;   // [ASSUMPTION] mm - Shoulder wall (4 perimeters); hosts radial heat-set inserts.
NC_SPLIT         = 150.0;   // [ASSUMPTION] mm - Print split station so each half fits a 250 mm Z-height printer.
NC_BH_T          = 6.0;   // [ASSUMPTION] mm - Printed nose bulkhead / ballast mount thickness.
BALLAST_ROD_L    = 80.0;   // [ASSUMPTION] mm - M6 A2 threaded rod length forward of NC-103 (rod is cut to BALLAST_ROD_L + NC_BH_T = 86).
NC_TIP_SOLID     = 8.0;   // [ASSUMPTION] mm - Solid printed tip before the internal cavity starts (CAD rev B).
NC_SPIGOT_L      = 10.0;   // [ASSUMPTION] mm - NC-101 spigot length aft of the print split (engages NC-102 socket).
NC_SPLIT_WEB     = 2.0;   // [ASSUMPTION] mm - Solid annular web closing NC-101 at the split; the spigot grows from it (CAD rev B, printable).
NC_SPIGOT_WALL   = 1.6;   // [ASSUMPTION] mm - Spigot wall thickness.
FIT_SOCKET       = 0.2;   // [ASSUMPTION] mm - Diametral clearance spigot-to-socket (I-00, slip fit +0.1/+0.3).
NC_BASE_RING     = 1.6;   // [ASSUMPTION] mm - Closing ring between ogive wall and shoulder at the nose base.
NC_BOSS_T        = 4.4;   // [ASSUMPTION] mm - Radial insert boss depth inside the shoulder (wall + boss = 6.0 >= insert + 0.5).
NC_LUG_L         = 12.0;   // [ASSUMPTION] mm - NC-103 mounting lug length (lugs end at the bulkhead forward face, CAD rev B).
NC_LUG_T         = 6.0;   // [ASSUMPTION] mm - NC-103 mounting lug radial depth.
NC_SCREW_ANG     = [90, 210, 330];   // [ASSUMPTION] deg - Angular positions of the 3 radial nose screws (I-01).
NC_LUG_ANG       = [30, 150, 270];   // [ASSUMPTION] deg - Angular positions of the 3 NC-103 lugs.
PL_L             = 250.0;   // [ASSUMPTION] mm - Payload tube length. Clear payload bay = PL_L - NC_SH_L - AV insertion - bulkheads.
CAM_LENS_HOLE    = 14.0;   // [USER-SUPPLIED] mm - Set from the chosen camera's lens barrel diameter + 1 mm.
CAM_MASS         = 35.0;   // [USER-SUPPLIED] g - Weigh the chosen camera (with its cable). 35 g is a planning placeholder.
CAM_OFF          = 36.0;   // [ASSUMPTION] mm - Camera lens-hole station aft of the nose shoulder end (STA 360).
CAM_ANG          = 270;   // [ASSUMPTION] deg - Camera / lens-cowl angular position.
CAM_TILT         = 15.0;   // [ASSUMPTION] deg - Lens axis tilted aft from radial (matches the PL-204 window).
CAM_W            = 26.0;   // [USER-SUPPLIED] mm - Camera body width (PLACEHOLDER: measure your camera). Rev B: 29 -> 26; the rev A 29 x 16 x 45 placeholder interfered with the tube wall at 15 deg tilt.
CAM_H            = 14.0;   // [USER-SUPPLIED] mm - Camera body depth along the lens axis (PLACEHOLDER; rev A 16).
CAM_LEN          = 40.0;   // [USER-SUPPLIED] mm - Camera body length (PLACEHOLDER; rev A 45). The CAD re-seats any size inside the bore; the pipeline then checks tray clearance.
CAM_LENS_L       = 5.0;   // [USER-SUPPLIED] mm - Lens barrel protrusion from the camera face (PLACEHOLDER).
HATCH_OFF        = 71.0;   // [ASSUMPTION] mm - Hatch centre station aft of the nose shoulder end (STA 395).
HATCH_ANG        = 90;   // [ASSUMPTION] deg - Hatch angular position (over the GPS).
HATCH_W          = 25.0;   // [ASSUMPTION] mm - Hatch cut-out chord width.
HATCH_L          = 40.0;   // [ASSUMPTION] mm - Hatch cut-out axial length.
HATCH_GAP        = 0.3;   // [ASSUMPTION] mm - Edge gap between hatch panel and cut-out.
HATCH_SCREW_OFF  = 17.0;   // [ASSUMPTION] mm - Hatch screws at hatch centre +/- this (on the frame ledges).
FRAME_L          = 54.0;   // [ASSUMPTION] mm - PL-206 doubler frame axial length.
FRAME_W          = 40.0;   // [ASSUMPTION] mm - PL-206 doubler frame chord width.
FRAME_T          = 2.0;   // [ASSUMPTION] mm - PL-206 frame thickness (bosses 4.5).
TRAY_L           = 90.0;   // [ASSUMPTION] mm - PL-202 overall length including the foot.
TRAY_W           = 50.0;   // [ASSUMPTION] mm - PL-202 plate width.
TRAY_T           = 2.5;   // [ASSUMPTION] mm - PL-202 plate thickness.
TRAY_FOOT_T      = 8.0;   // [ASSUMPTION] mm - PL-202 foot thickness (bears on AV-303).
TRAY_HOLE_X      = 7.0;   // [ASSUMPTION] mm - Tray screw holes at x = +/- this (CAD rev B: clears tee-nut flanges).
TRAY_HOLE_Y      = -14.0;   // [ASSUMPTION] mm - Tray screw holes at y = this (below the sled plane).
AV_CPL_L         = 170.0;   // [ASSUMPTION] mm - Coupler length = 70 insertion + 30 switch band + 70 insertion.
AV_INS           = 70.0;   // [ASSUMPTION] mm - Coupler insertion each side (~1.1 calibre; >= 1 calibre is the usual rule of thumb).
AV_BAND_L        = 30.0;   // [ASSUMPTION] mm - Switch band length (exposed airframe ring).
AV_BH_T          = 6.0;   // [ASSUMPTION] mm - Each bulkhead disc thickness (birch ply); 2 discs per bulkhead.
AV_ROD_SP        = 40.0;   // [ASSUMPTION] mm - Threaded-rod spacing (M4) in the sled plane.
SLED_L           = 140.0;   // [ASSUMPTION] mm - Electronics sled length.
SLED_W           = 52.0;   // [ASSUMPTION] mm - Electronics sled width (fits CPL_ID with rod sleeves).
SLED_T           = 3.0;   // [ASSUMPTION] mm - Sled thickness (PETG, 100% infill between rod sleeves).
SLED_FWD_GAP     = 7.0;   // [ASSUMPTION] mm - Gap AV-303 to sled = forward AV-312 spacer length.
GASKET_T         = 0.5;   // [ASSUMPTION] mm - AV-309 face gasket compressed thickness (1.5 mm foam free). CAD rev B: moves AV-304 outer disc aft by this.
SW_ANG           = 90;   // [ASSUMPTION] deg - Arming-switch access angle.
SW_HOLE_D        = 8.0;   // [ASSUMPTION] mm - Switch access hole through AV-302 + AV-301.
SW_TOWER_H       = 20.0;   // [USER-SUPPLIED] mm - Switch tower height above sled; set so the switch actuator sits ~1 mm below CPL_ID.
STATIC_PORT_D    = 2.0;   // [ASSUMPTION] mm - 4 static ports at 45/135/225/315 deg (size per sensor maker guidance).
HARNESS_D        = 8.0;   // [ASSUMPTION] mm - Harness hole through AV-303 (grommet).
HARNESS_Y        = 14.0;   // [ASSUMPTION] mm - Harness hole centre offset toward the switch side (+Y).
BAT_L            = 55.0;   // [USER-SUPPLIED] mm - Battery length (PLACEHOLDER: set from purchased cell).
BAT_W            = 28.0;   // [USER-SUPPLIED] mm - Battery width (PLACEHOLDER; max 28.8 to clear the rod sleeves).
BAT_H            = 9.0;   // [USER-SUPPLIED] mm - Battery thickness (PLACEHOLDER).
ROD_L            = 190.0;   // [ASSUMPTION] mm - AV-305 M4 rod length (fwd bulkhead face to 1.7 mm past the aft nut).
BO_L             = 600.0;   // [ASSUMPTION] mm - Booster tube length (recovery bay + fin can).
MMT_OD           = 31.0;   // [ASSUMPTION] mm - 29 mm-class motor mount tube OD. Measure purchased tube.
MMT_ID           = 29.0;   // [COMMERCIAL SPEC] mm - PLACEHOLDER ONLY (MMT bore for the motor casing). Replace via simulation/motor_config.json with the selected certified product's published data.
MMT_L            = 260.0;   // [COMMERCIAL SPEC] mm - PLACEHOLDER ONLY (MMT length >= longest motor + retainer requirement). Replace via simulation/motor_config.json with the selected certified product's published data.
MMT_AFT_EXT      = 10.0;   // [COMMERCIAL SPEC] mm - PLACEHOLDER ONLY (MMT protrusion aft of airframe for the retainer). Replace via simulation/motor_config.json with the selected certified product's published data.
CR_T             = 6.0;   // [ASSUMPTION] mm - Forward centering ring thickness (birch ply, recovery-load anchor ring).
CORE_RING_T      = 8.0;   // [ASSUMPTION] mm - Fin-can core ring thickness (ASA print).
CORE_RAIL_T      = 1.6;   // [ASSUMPTION] mm - Fin guide rail thickness.
LOCK_T           = 6.0;   // [ASSUMPTION] mm - Aft fin lock ring thickness (birch ply: heat tolerant near motor).
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

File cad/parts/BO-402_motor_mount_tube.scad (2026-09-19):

// ASTRA-66 CAD rev B -- BO-402 Motor mount tube (external propulsion interface I-05)
// MMT_ID, MMT_L and MMT_AFT_EXT are COMMERCIAL SPEC placeholders: take final values from the certified
// motor system's and retainer's current documentation. Nothing here specifies a motor.
include <../lib/astra66_core.scad>

module BO_402_motor_mount_tube() { tube_r(R_MO, R_MI, X_MMT_FWD, X_MMT_AFT); }

BO_402_motor_mount_tube();

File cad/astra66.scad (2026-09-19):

// =============================================================================
// ASTRA-66 -- compatibility entry point (rev A interface, rev B geometry)
// The master CAD file is cad/assembly/astra66_assembly.scad; part sources are in cad/parts/.
// This file keeps the rev A `PART=` selector used by tools/openscad_render_check.py.
//   PART = "assembly" | "exploded" | "nose_tip" | "nose_base" | "nose_bulkhead" | "camera_cradle"
//        | "lens_cowl" | "hatch" | "hatch_frame" | "gps_tray" | "sled" | "bulkhead_fwd" | "bulkhead_aft"
//        | "fwd_centering_ring" | "fincan_core" | "lock_ring" | "fin" | "rail_boss" | "fin_jig"
// =============================================================================
include <lib/astra66_core.scad>
use <parts/NC-101_nose_tip.scad>
use <parts/NC-102_nose_base.scad>
use <parts/NC-103_nose_bulkhead.scad>
use <parts/PL-202_gps_tray.scad>
use <parts/PL-203_camera_cradle.scad>
use <parts/PL-204_lens_cowl.scad>
use <parts/PL-205_access_hatch.scad>
use <parts/PL-206_hatch_frame.scad>
use <parts/AV-303_fwd_bulkhead.scad>
use <parts/AV-304_aft_bulkhead.scad>
use <parts/AV-306_electronics_sled.scad>
use <parts/BO-403_fincan_core.scad>
use <parts/BO-404_fwd_centering_ring.scad>
use <parts/BO-405_fin_lock_ring.scad>
use <parts/BO-406_fin.scad>
use <parts/BO-409_rail_button_boss.scad>
use <parts/GS-701_fin_jig.scad>
use <assembly/astra66_assembly.scad>

PART    = "assembly";
EXPLODE = 90;

if (PART == "assembly")                oriented() astra66(0);
else if (PART == "exploded")           oriented() astra66(EXPLODE);
else if (PART == "nose_tip")           NC_101_nose_tip();
else if (PART == "nose_base")          NC_102_nose_base();
else if (PART == "nose_bulkhead")      NC_103_nose_bulkhead();
else if (PART == "camera_cradle")      PL_203_camera_cradle();
else if (PART == "lens_cowl")          PL_204_lens_cowl();
else if (PART == "hatch")              PL_205_access_hatch();
else if (PART == "hatch_frame")        PL_206_hatch_frame();
else if (PART == "gps_tray")           PL_202_gps_tray();
else if (PART == "sled")               AV_306_electronics_sled();
else if (PART == "bulkhead_fwd")       AV_303_fwd_bulkhead();
else if (PART == "bulkhead_aft")       AV_304_aft_bulkhead();
else if (PART == "fwd_centering_ring") BO_404_fwd_centering_ring();
else if (PART == "fincan_core")        BO_403_fincan_core();
else if (PART == "lock_ring")          BO_405_fin_lock_ring();
else if (PART == "fin")                BO_406_fin(0);
else if (PART == "rail_boss")          BO_409_rail_button_boss();
else if (PART == "fin_jig")            GS_701_fin_jig();

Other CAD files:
cad/exports/dxf/BO-404_forward_centering_ring.dxf
cad/exports/stl/PL-205_access_hatch.stl
cad/exports/dxf/AV-303-inner_forward_bulkhead_2_discs.dxf
cad/exports/stl/NC-103_nose_bulkhead_ballast_mount.stl
cad/assembly/astra66_assembly.scad
cad/exports/stl/AV-306_electronics_sled.stl
cad/exports/stl/AV-312-aft_rod_spacers_2_fwd_2_aft.stl
cad/exports/stl/GS-701_fin_alignment_jig_ground_support.stl
cad/exports/stl/NC-101_nose_tip_section.stl
cad/exports/stl/NC-102_nose_base_shoulder.stl
cad/exports/stl/PL-203_camera_cradle.stl
cad/exports/stl/PL-204_lens_cowl.stl
cad/parts/AV-301_coupler.scad
cad/parts/AV-302_switch_band.scad
cad/parts/AV-303_fwd_bulkhead.scad
cad/parts/AV-304_aft_bulkhead.scad
cad/parts/AV-306_electronics_sled.scad
cad/parts/AV-308_battery_cage.scad
cad/parts/AV-309_gasket.scad
cad/parts/AV-312_rod_spacers.scad
cad/parts/BO-401_booster_tube.scad
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

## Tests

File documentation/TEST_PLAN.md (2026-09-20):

# ASTRA-66 — Test plan (master index)

> What is tested today, and what is planned but **not performed**. No physical test, bench measurement or flight has
> taken place; no result below is invented. Propulsion is an external, commercially certified component and is not
> tested here in any form. ASTRA-66 is NOT FLIGHT CERTIFIED.

Status vocabulary: **DONE** (automated, reproducible, in CI) · **PLANNED** (written down, not performed) ·
**BLOCKED** (needs hardware or a qualified mentor first).

## 1. Software tests — DONE (155 automated tests)

| Group | Where | Examples of what is checked |
|---|---|---|
| Package and data consistency | `tests/test_export.py`, `tests/test_cad.py` | Rebuilt outputs match the committed ones; CAD data and drawings are consistent and parse |
| Simulation | `tests/test_simulation.py` | Verification checks pass; placeholder status is flagged in the results |
| Documentation | `tests/test_docs.py` | Every quoted file path exists; disclaimers present in the key documents |
| Avionics integration | `tests/test_avionics.py` | Packet encode/decode, CRC, every single-bit corruption rejected, sequence and loss accounting, sensor validity and staleness, missing GPS, impossible values, barometric conversion, estimator behaviour, state transitions, logging format, replay of recorded data, data-source modes, bench template, documentation claims |
| Avionics software | `avionics/tests/` (8 modules) | Schema validation, sensor scheduling and fault injection, timestamp wrap/duplicate/gap, damaged log files, classifier against synthetic truth, telemetry, logging, analysis mathematics, ground-station server, and the safety-boundary scan |

Run: `python -m unittest discover -s tests` and `python -m unittest discover -s avionics/tests -t .`

## 2. CAD checks — DONE (147 PASS · 12 accepted WARN · 0 FAIL)

Measured on the rendered meshes: manifold geometry, volumes and centroids, 44 interference pairs, 11 interface
checks, assembly feasibility (sled removal, joint separation, fin removal with the retainer fitted, motor insertion),
printability and wall thickness, electronics fit, and 15 dimensions cross-checked against the analysis.

Run: `python run_validation.py --with-cad --openscad <path>` (needs OpenSCAD 2021.01; the default run verifies that
the committed validation is still current).

The 12 warnings are accepted and documented: 11 printed parts need support in the chosen pose, and the hatch panel
wall is 1.0 mm (0.25 mm nozzle recommended).

## 3. Simulation checks — DONE (13/13)

Closed-form and independent cross-checks: ISA density and speed of sound, impulse quadrature, motor mass after
burnout, constant-thrust burnout altitude and apogee, parachute terminal velocity, time-step convergence, liftoff
mass and CG against the analysis, independent Barrowman CP, and a drag plausibility band.

These verify the software. With placeholder propulsion the trajectory is illustrative, not a prediction.

## 4. Avionics replay checks — DONE

A synthetic sensor dataset with five scripted faults is replayed through the real pipeline: events detected close to
the known truth, impossible values rejected before processing, sensor staleness and recovery observed, telemetry
generated, corrupted packets rejected, lost packets counted.

Run: `python simulation/avionics_replay.py`

## 5. Bench tests — PLANNED / BLOCKED (no hardware exists)

Fourteen electronics-and-software tests, B-01…B-14, are specified in `AVIONICS_BENCH_TEST_PLAN.md`: power-up,
sensor detection, IMU sanity, pressure sanity, GNSS acquisition, data logging, packet generation, packet integrity,
ground-station link, packet-loss handling, timestamp consistency, battery monitoring, long-duration logging,
power-down data preservation.

Blocked until components are selected with a mentor (`HARDWARE_SELECTION_CHECKLIST.md`). Each test records raw data
as `BENCH` with a meta file (`../avionics/bench_data/README.md`) and is processed by the same software as synthetic
data, so bench and simulation results can be compared directly.

## 6. Hardware integration tests — PLANNED / BLOCKED

After the bench phase, still without flying:

| Test | Purpose |
|---|---|
| Physical fit | Real boards, wiring and connectors in the printed sled and bay; sled removal margin re-checked |
| Mass and CG | Weigh every item and each module; measure the vehicle CG (`MASS_MEASUREMENT_PROCEDURE.md`) |
| Structural fit coupons | Printed shoulder, fin guide slot and heat-set inserts |
| Bay sealing | Static-port response and leak behaviour with the selected barometer |
| Harness | Continuity, strain relief, connector passage through the ⌀8 mm grommet |
| Separation sense | Breakwire continuity and logging when the joint is separated by hand |
| Hardware-in-the-loop | Bench data replayed against the simulation; estimator and classifier behaviour compared |
| Pipeline re-validation | Update the CAD envelopes and masses, re-run `run_validation.py --with-cad` |

## 7. Supervised physical testing — BLOCKED (mentor and range)

Not a software decision and not planned in detail here. It requires, at minimum: a legally obtainable certified motor
selected and handled by a certified person; its published data replacing the placeholders, with the stability and
rail-exit checks redone; recovery hardware proof loads; a complete flight-readiness review; and range safety officer
approval on the day. Radio operation needs a legal band and power and range frequency coordination.

Nothing in this repository authorises or describes motor preparation, ignition or any energetic device.

## 8. Current results summary

| Category | Status | Evidence |
|---|---|---|
| Software tests | 155 pass | CI on Python 3.12 and 3.14 |
| CAD checks | 147 PASS · 12 WARN · 0 FAIL | `CAD_VALIDATION.md` |
| Simulation checks | 13/13 | `SIMULATION_VALIDATION.md` |
| Replay checks | pass | `simulation/results/avionics_replay/replay_events.json` |
| CAD fit / mass check | 11 PASS · 4 WARN · 8 UNVERIFIED · 0 FAIL | `CAD_AVIONICS_INTEGRATION.md` |
| Bench tests | **not performed** | — |
| Hardware integration tests | **not performed** | — |
| Flight testing | **not performed** | — |

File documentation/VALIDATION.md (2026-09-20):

# ASTRA-66 — What is validated, and what is not

> **NOT FLIGHT CERTIFIED.** Everything below is software, CAD-model and numerical validation. No physical test,
> measurement or flight has taken place. Propulsion is an external, commercially certified component; its data here
> are placeholders, so every trajectory number is illustrative.

## 1. The one command

```bash
python run_validation.py          # add --with-cad --openscad <path> to re-render the CAD as well
```

| # | Step | What it proves | Current result |
|---|---|---|---|
| 1 | Engineering package build | The parameters, mass budget, BOM, drawings and package regenerate from `analysis/analysis.py` | PASS |
| 2 | CAD integration | The committed CAD validation matches every current `.scad` source and parameter (hash check); with `--with-cad` the model is re-rendered and re-measured | PASS — 147 PASS · 12 accepted WARN · 0 FAIL |
| 3 | Flight simulation | Trajectory, stability and sensitivity regenerate; numerical verification passes | PASS — 13/13 checks |
| 4 | Avionics sensor replay | A recorded sensor dataset runs through the real flight-computer pipeline and produces the expected events and validity | PASS |
| 5 | CAD fit and mass properties | Electronics envelopes fit the CAD; the CG recomputed from the mass budget matches the analysis | PASS — 11 PASS · 4 WARN · 8 UNVERIFIED · 0 FAIL |
| 6 | Project regression tests | 74 tests: package, CAD data, simulation, documentation, avionics integration | PASS |
| 7 | Avionics software tests | 81 tests: sensors, timestamps, corrupted data, state machine, telemetry, logging, analysis, safety boundary | PASS |

GitHub Actions runs exactly this on Python 3.12 and 3.14 for every push and pull request.

## 2. Automated tests (155 total)

| Suite | Count | Covers |
|---|---|---|
| `tests/` project regression | 74 | Package build outputs match the committed ones; CAD data consistency; simulation results and placeholder flags; documentation references and disclaimers; avionics integration (packets, CRC, sequence handling, sensor validity, missing GPS, impossible values, barometric conversion, estimator, state transitions, log format, replay, data-source modes, bench template, Phase 6 documents) |
| `avionics/tests/` | 81 | Schema validation, sensor scheduling and fault injection, timestamp wrap/duplicates/gaps, damaged log files, flight-state classification against a synthetic truth, telemetry encode/decode and corruption, logging formats and metadata, post-flight analysis mathematics, architecture and safety-boundary checks, ground-station server |

Two habits keep these meaningful: no test was ever relaxed to make a build pass, and the safety boundary is enforced
by a test that scans every avionics source for actuation-style identifiers and hardware-I/O imports.

## 3. CAD checks (what the model actually shows)

Measured on the **rendered meshes**, not on drawings:

- closed-manifold geometry for every part; volumes, centroids, bounding boxes;
- interference across 44 part pairs (0 interferences) and 11 interface checks;
- assembly feasibility: sled removal, nose removal, joint separation, motor insertion, fin removal with the retainer
  fitted (a real defect was found and fixed this way in an earlier revision);
- printability (overhang area, bed fit) and wall thicknesses;
- electronics: sled stack radius vs coupler bore, battery width, GPS under the hatch, switch reach;
- 15 dimensions cross-checked against the analysis.

Result: 147 PASS, 12 accepted WARN (support-needing prints, one 1.0 mm hatch wall), 0 FAIL. A full re-render with
OpenSCAD 2021.01 reproduces the same result and geometry (volumes agree to ~1e-14 relative), though the exported
files are not byte-identical (float formatting and the render date).

## 4. Simulation checks

13 numerical verification checks, each comparing the simulation against something independent:

ISA density at 0 m and 11 km, ISA speed of sound, thrust-curve impulse by fine quadrature, motor mass after burnout,
burnout altitude and apogee for a constant-thrust drag-free case (closed form), parachute terminal velocity,
time-step convergence, liftoff mass and CG against the analysis, CP by an independent Barrowman calculation on
CAD-measured geometry, and a drag-coefficient plausibility band.

These verify the **software**. They do not validate the vehicle's real behaviour, and with placeholder propulsion the
trajectory itself is not a prediction.

## 5. Avionics replay checks

A deterministic synthetic sensor dataset (2162 rows, 50 Hz, with five scripted faults) is replayed through the same
flight-computer code that would run on hardware:

- all four flight events detected close to the known truth (liftoff +0.02 s, apogee within 0.01 s and 0.04 m, landing
  −0.18 s);
- the three impossible values (NaN acceleration, 250 kPa pressure, 9.9 V battery) are rejected before processing and
  flagged in the log;
- the GNSS dropout and the silent temperature sensor show as stale and then recover;
- telemetry packets are produced, corrupted packets are rejected, and lost packets are counted.

## 6. What is **not** validated

| Area | Status |
|---|---|
| Any sensor, microcontroller, radio, battery or storage device | No component selected; nothing bought, measured or tested |
| Physical fit of real boards, wiring, connectors, antenna | UNVERIFIED — needs measurement (8 open items) |
| Masses and centre of gravity | All avionics masses are estimates; nothing has been weighed |
| Motor performance, thrust curve, ejection | Placeholder data; the real motor is a mentor's selection |
| Recovery deployment, parachute descent | Never tested |
| Structural strength | Hand calculations only; no FEA, no coupon tests |
| Aerodynamic drag | Uncalibrated build-up; no wind-tunnel or flight data |
| Radio range, link margin, legality | Not assessed |
| Real-time ground-station behaviour | Prototype on replayed data only |
| Flight behaviour of the vehicle | Nothing has flown |

Full classification: `HARDWARE_INTEGRATION_STATUS.md`. Planned physical work: `TEST_PLAN.md` and
`AVIONICS_BENCH_TEST_PLAN.md`.

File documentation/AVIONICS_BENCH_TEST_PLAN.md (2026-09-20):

# ASTRA-66 — Avionics bench-test plan (electronics and software only)

> **Scope: a bench, a laptop and the avionics electronics.** No motor, no igniter, no pyrotechnics, no energetic
> device and no deployment hardware are involved in any step; the avionics have no output that could drive one.
> Propulsion stays an external, commercially certified component and is not part of any test here. Nothing in this
> plan makes ASTRA-66 flight certified: the project is **NOT FLIGHT CERTIFIED**, and passing every test proves only
> that the electronics and software behave as specified on the bench.
>
> **Nothing below has been performed.** No hardware exists yet (`documentation/HARDWARE_INTEGRATION_STATUS.md`).

## How to run and record a test

1. Select the components first (`documentation/HARDWARE_SELECTION_CHECKLIST.md`); a test without a recorded part and
   datasheet is not evidence.
2. Record raw data in the standard sensor-level format with `data_source = BENCH` and a meta file
   (`avionics/bench_data/README.md`).
3. Process the recording with the same pipeline used for synthetic data, so the software path is identical:
   `python simulation/avionics_replay.py avionics/bench_data/<record>.csv --out simulation/results/<name>`.
4. Write the outcome (pass / fail, measured numbers, anomalies) into the bench record's meta file; never edit measured
   values.
5. Work with a second person present for anything involving LiPo charging, and follow the range's battery rules.

Safety on the bench: keep the battery disconnected while wiring; check polarity before the first power-up; treat every
GPIO as input-only; if the radio is used, transmit only on a band and at a power level legal where you are.

## Tests

| ID | Test | Objective | Outline | Pass criteria (targets, to be agreed with the mentor) | Evidence |
|---|---|---|---|---|---|
| B-01 | Power-up verification | The board powers up safely on the intended supply | Bench supply or charged cell at nominal voltage, current meter in series; power through the AV-307 switch; observe the buzzer / LED annunciation | No component above its rated temperature; current draw within the budget; switch reliably powers the electronics on and off; no brown-out at the lowest planned cell voltage | Measured idle and active current; photo of the setup; notes |
| B-02 | Sensor detection | Every selected sensor is found on its bus and responds | Scan I²C / SPI / UART at start-up; read one sample from each sensor; unplug one sensor and repeat | All expected devices detected; the flight computer reports a missing sensor as unhealthy instead of failing; breakwire continuity reads correctly (open and closed) | Start-up log; health flags |
| B-03 | IMU data sanity | Accelerometer and gyro produce physically sensible values | With the bay stationary, log 60 s in six orientations (±x, ±y, ±z up); rotate slowly by a known angle about each axis | Magnitude ≈ 1 g at rest in every orientation; axis signs match the +z-toward-nose convention; gyro bias and noise recorded; integrated rotation within a few per cent of the applied angle | Bench record + measured bias / noise table |
| B-04 | Pressure sensor sanity | Barometric pressure and derived altitude behave correctly | Log at rest; compare with a reference barometer or local QNH; move the bay a known height (stairwell, lift); optionally a slow syringe / bag test on the sealed bay | Reading within the sensor's stated accuracy of the reference; a known height change gives the right altitude change within the agreed tolerance; noise at rest recorded | Bench record; reference readings |
| B-05 | GNSS acquisition | The receiver gets and keeps a usable fix | Cold start outdoors; warm start; repeat with the module inside the assembled airframe; then with the radio transmitting | Time to first fix recorded for each case; fix type and satellite count logged; fix retained (or documented loss) with the radio active | Bench record; times and satellite counts |
| B-06 | Data logging | Frames reach the card intact at the target rate | Log at the target rate for several minutes while all sensors run | No missing sequence numbers; every row's CRC-16 verifies; frames written = frames expected within the agreed margin | Log file + reader report (`read_flight_log`) |
| B-07 | Packet generation | Telemetry packets are produced correctly from live data | Run the flight computer with the radio disabled but packets captured over USB | Packet rate as configured; fields match the log within quantisation; SIMULATED flag clear on real data; health bits follow the sensors | Captured packets; decoder output |
| B-08 | Packet integrity | Corrupted packets are detected, never accepted | Inject bit errors in the capture (offline) and repeat with a real link if available | Every corrupted packet rejected by CRC; no corrupted packet reaches the display | Receiver statistics |
| B-09 | Receiver / ground-station communication | The ground station shows live data from the real link | Airborne module and ground module at bench distance; run `avionics/ground_station/server.py`; then repeat at increasing distance | Dashboard updates continuously; values match the onboard log; link statistics plausible; measured usable range recorded | Screenshot; received-telemetry log |
| B-10 | Packet-loss handling | Loss is measured and displayed, never hidden | Move out of range / shield the antenna; return | Missing sequence numbers counted; display marks stale data; no false values shown; recovery works | Link statistics over the run |
| B-11 | Timestamp consistency | The time base is monotonic and correctly scaled | Log for longer than one counter wrap if the counter is 32-bit µs (~72 min); compare elapsed log time with a stopwatch | Timestamps strictly increasing; no duplicates; wrap handled; drift against wall-clock time recorded | Long log + reader report |
| B-12 | Battery monitoring | Reported voltage matches reality | Compare the logged voltage with a multimeter from full charge down to the agreed cut-off, including while transmitting | Agreement within the agreed tolerance across the range; sag under transmit recorded | Calibration table |
| B-13 | Long-duration logging | The system survives a realistic pad hold | Run a full pad-hold duration (target from the mission plan) with all sensors, logging and telemetry active | No data gaps beyond the agreed limit; card not full; temperature stable; battery endurance with margin | Long bench record; endurance figure |
| B-14 | Power-down / data preservation | An unexpected power cut does not destroy the log | Pull power at a random time during logging; repeat several times; then read the card | The file is readable; at most the final row is damaged, and the reader reports it; no earlier rows corrupted | Reader report per trial |

## Exit criteria for the bench phase

- B-01…B-14 executed with the selected hardware, each with a bench record and a meta file.
- Every measured value that the analysis uses (masses, dimensions, endurance) entered through the documented workflow
  (`documentation/MASS_MEASUREMENT_PROCEDURE.md`) and the pipeline re-run.
- Remaining open items listed honestly in `documentation/HARDWARE_INTEGRATION_STATUS.md`.
- A mentor has reviewed the results. Flight remains subject to a complete flight-readiness review and range approval;
  the bench phase alone never makes the project flight certified.

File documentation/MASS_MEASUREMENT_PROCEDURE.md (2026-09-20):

# ASTRA-66 — Mass and centre-of-gravity measurement procedure

> **No mass in this repository has been measured.** Every value in `analysis/analysis.py` is CALCULATED (CAD volume ×
> assumed density × fill) or an ASSUMPTION, and the CG and static margin follow from them. This procedure defines how
> to record real measurements so the existing analysis consumes them. Do not enter a value that was not measured, and
> do not adjust a measurement to match a prediction. The project stays NOT FLIGHT CERTIFIED.

## 1. Reference datum and conventions

| Convention | Definition |
|---|---|
| Datum (STA 0) | The nose tip, on the rocket axis. Stations increase **aft**; the airframe ends at STA 1144 mm |
| Station of a part | Distance from the datum to the part's own centre of gravity, along the axis |
| Mass unit | grams (g), one decimal |
| Length unit | millimetres (mm), one decimal |
| Orientation | Record the orientation used for every CG measurement (nose up / horizontal) |

Existing station values are in `analysis/results/mass_budget.csv` (column `cg_station_mm`) and, for the avionics items,
in `avionics/integration/avionics_mass_properties.csv`.

## 2. Equipment

- Scale: resolution ≤ 0.1 g for parts, ≤ 1 g for the assembled rocket; record make, model and resolution.
- Calibration check before each session with a known mass; record the check result.
- Steel rule or calliper for stations (≤ 0.5 mm resolution), and a knife-edge or a round bar for the balance method.
- Two people for the assembled-vehicle measurements.

## 3. Individual component mass

Weigh every item **as it will fly**: printed parts after cleaning and any paint, boards with headers, connectors and
the wiring that belongs to them, fasteners in their sets.

Record one row per item:

| Field | Example / rule |
|---|---|
| `id` | the existing part or module id (`AV-306`, `EL-AV`, `EL-BAT`, …) so it maps onto the mass budget |
| `description` | what was actually weighed, including what was attached |
| `mass_g` | measured value, one decimal |
| `uncertainty_g` | scale resolution, or the spread if weighed more than once |
| `station_mm` | measured or CAD station of the item's CG (state which) |
| `date`, `operator` | when and who |
| `notes` | anything unusual (wet paint, missing screw, substituted part) |

Weigh sub-assemblies that are hard to separate as one item and say so, instead of splitting the mass by guesswork.

## 4. Assembled avionics mass

1. Assemble the sled exactly as it will fly: boards, standoffs, wiring, battery, cage, switch, breakwire tails.
2. Weigh the complete sled assembly (`EL-AV` + `AV-306` + `AV-308` + `EL-BAT` + fasteners) as one number.
3. Weigh the payload-bay electronics (`EL-GPS`, tray, camera if fitted) as one number.
4. Compare each total with the sum of the individual items from §3: they should agree within the summed uncertainty.
   If they do not, find the missing item before entering anything.

## 5. Total dry mass

Dry mass = the complete vehicle ready to fly **without the motor** and without the recovery charge (there is none in
this design: the certified motor's own ejection is used). Weigh:

1. Each module separately (nose, payload bay, avionics bay, booster) with everything installed.
2. The fully assembled vehicle, motor tube empty.
3. Note what is not yet fitted (paint, decals, ballast) and repeat when it is.

## 6. Centre of gravity

**Balance method (primary).**

1. Rest the assembled vehicle horizontally on a knife-edge or a round bar, fins clear of the surface.
2. Slide until it balances; mark the point and measure its distance from the nose tip (the datum): that is the CG
   station. Repeat three times and record all three readings, not just the mean.
3. Repeat with the motor casing fitted **only when a mentor is present and the motor is inert / not loaded**, and
   record it as a separate line. A loaded motor is handled by a certified person only.

**Moment method (cross-check).**

Support the vehicle at two points a known distance apart, weigh each support, and compute the CG from the moments.
Agreement with the balance method within a few millimetres is expected; record both.

## 7. Entering measurements into the analysis

The analysis is the single source of truth; measured values replace assumptions there, and everything downstream
(mass budget, CG, static margin, simulation, CAD mass cross-check) is regenerated by the pipeline.

1. Edit the relevant `add(...)` line in `analysis/analysis.py`: put the measured mass in place of the assumption and
   set its provenance tag to `USER` (the project's tag for a value you supply, "measured part"; the tags are `CALC`,
   `ASM`, `USER` and `COTS`, defined at the top of that file). Put the date, the scale and the measured uncertainty in
   the note argument, e.g. `"weighed 2026-10-01, 0.1 g scale, 58.4 +/- 0.1 g"`, so the mass budget shows where the
   number came from.
2. If a part's CG station was measured rather than taken from the CAD, update the station argument too.
3. Re-run the pipeline: `python run_validation.py`. It regenerates `analysis/results/mass_budget.csv`, the CG and
   static margin, the simulation results and the CAD ↔ avionics mass report.
4. Check the results that matter:
   - liftoff CG and static margin against the 1.5–3.0 calibre target (`documentation/ENGINEERING_STATUS.md`);
   - the recomputed CG against the measured CG from §6: they should agree within the measurement uncertainty. A
     disagreement means an item is missing or mis-stationed — investigate, do not tune the numbers;
   - the avionics table `avionics/integration/avionics_mass_properties.csv` for the effect of each item on the CG.
5. Record the measurement session (who, when, scale, results) alongside the bench records so the change is traceable.

## 8. What stays open after this procedure

- Static margin with the **certified motor** fitted: needs the motor's published mass and the measured CG
  (**mentor review**).
- Any mass that could not be weighed (for example a part not yet made) stays an assumption and must remain tagged as
  one.
- Measured masses do not make the design flight certified: the flight-readiness review and range approval are separate.

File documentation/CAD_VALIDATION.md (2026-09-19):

# ASTRA-66 — CAD validation report (rev B)

> Draft design data for a student project. **Not flight certified.** Propulsion is an external, certified commercial component, shown only as a placeholder envelope. Final motor, retainer and hardware dimensions must come from the manufacturers' current documentation, and the design must be reviewed by a qualified rocketry mentor or institution before any flight.

**Result: 147 PASS · 12 WARN · 0 FAIL**  (validation date 2026-09-19, generated by `cad/build_cad.py`, runtime 141 s)

Scope: 30 OpenSCAD files · 25 designed parts + 11 commercial envelopes · exports: 15 print STL, 8 DXF + 8 SVG cut profiles, 2 assembly STL, 31 drawing sheets, 4 images · motor data status: **PLACEHOLDER**

## 0. Failed and warning checks (final run)

| Group | Item | Status |
|---|---|---|
| walls | PL-205 hatch panel (= tube wall) | WARN |
| printability | NC-101 | WARN |
| printability | NC-102 | WARN |
| printability | PL-202 | WARN |
| printability | PL-203 | WARN |
| printability | PL-204 | WARN |
| printability | PL-205 | WARN |
| printability | PL-206 | WARN |
| printability | AV-306 | WARN |
| printability | AV-308 | WARN |
| printability | BO-403 | WARN |
| printability | BO-409 | WARN |

**Failed checks: 0.** Every warning is an accepted, documented limitation (support material or a thin printed wall). Failures found by earlier validation runs are listed with their fixes in §6 (C-14 to C-16 came from the automated checks).

## 1. CAD version

| Item | Value |
|---|---|
| CAD revision | B (supersedes the unrendered rev A model in the engineering package) |
| CAD system | OpenSCAD version 2021.01 (CGAL kernel), official portable build; executable SHA-256 `8d1ee0c8272df474…` |
| Parameter source | `analysis/analysis.py` + `simulation/motor_config.json` → `build.py` → `cad/astra66_params.scad` (single source of truth) |
| CAD files checked | `cad/assembly/astra66_assembly.scad`<br>`cad/astra66.scad`<br>`cad/astra66_params.scad`<br>`cad/lib/astra66_core.scad`<br>`cad/parts/AV-301_coupler.scad`<br>`cad/parts/AV-302_switch_band.scad`<br>`cad/parts/AV-303_fwd_bulkhead.scad`<br>`cad/parts/AV-304_aft_bulkhead.scad`<br>`cad/parts/AV-306_electronics_sled.scad`<br>`cad/parts/AV-308_battery_cage.scad`<br>`cad/parts/AV-309_gasket.scad`<br>`cad/parts/AV-312_rod_spacers.scad`<br>`cad/parts/BO-401_booster_tube.scad`<br>`cad/parts/BO-402_motor_mount_tube.scad`<br>`cad/parts/BO-403_fincan_core.scad`<br>`cad/parts/BO-404_fwd_centering_ring.scad`<br>`cad/parts/BO-405_fin_lock_ring.scad`<br>`cad/parts/BO-406_fin.scad`<br>`cad/parts/BO-409_rail_button_boss.scad`<br>`cad/parts/COTS_envelopes.scad`<br>`cad/parts/GS-701_fin_jig.scad`<br>`cad/parts/NC-101_nose_tip.scad`<br>`cad/parts/NC-102_nose_base.scad`<br>`cad/parts/NC-103_nose_bulkhead.scad`<br>`cad/parts/PL-201_payload_tube.scad`<br>`cad/parts/PL-202_gps_tray.scad`<br>`cad/parts/PL-203_camera_cradle.scad`<br>`cad/parts/PL-204_lens_cowl.scad`<br>`cad/parts/PL-205_access_hatch.scad`<br>`cad/parts/PL-206_hatch_frame.scad` |
| Master assembly | `cad/assembly/astra66_assembly.scad` (MODE = assembly / exploded / section) |
| Part sources | `cad/parts/*.scad`: 25 parts + `COTS_envelopes.scad` |
| Facets | FN = 96 per circle |
| Reproduce | `python cad/build_cad.py --openscad <path to openscad>` |

## 2. Dimensions: CAD-measured vs analysis

| Dimension | CAD (mesh) | analysis.py | Δ | Status |
|---|---|---|---|---|
| Overall airframe length | 1144.0 | 1144.0 | 0.0 | PASS |
| Body OD (BO-401) | 66.0 | 66.0 | 0.0 | PASS |
| Nose exposed length (tip to shoulder) | 264.0 | 264.0 | 0.0 | PASS |
| Nose shoulder length | 60.0 | 60.0 | 0.0 | PASS |
| Fin span tip-to-tip | 186.0 | 186.0 | 0.0 | PASS |
| Fin root LE station | 994.0 | 994.0 | 0.0 | PASS |
| Fin tab depth below root line | 12.8 | 12.8 | 0.0 | PASS |
| Payload bay clear (NC-103 aft face to AV-303) | 114.0 | 114.0 | 0.0 | PASS |
| Avionics bay internal (AV-303 to AV-304 inner faces) | 158.5 | 158.5 | 0.0 | PASS |
| Recovery bay (AV-304 aft face to BO-404) | 273.5 | 273.5 | 0.0 | PASS |
| Coupler length | 170.0 | 170.0 | 0.0 | PASS |
| MMT stations | 894.0-1154.0 | 894.0-1154.0 | — | INFO |
| Rail buttons (station, angle) | 885.0 / 1115.0 @ 44.9 deg | 885.0 / 1115.0 @ 45 deg | — | INFO |
| Camera lens station / angle | 360.0 @ 270 deg (tilt 15.0) | 360.0 | — | INFO |
| GPS tray span | 348.0-438.0 | 348.0-438.0 | — | INFO |

## 3. Components

| Part | Source | Kind | Material | Volume cm³ | Mass g (total) | Z range mm | Triangles | Closed | CGAL simple | Exports |
|---|---|---|---|---|---|---|---|---|---|---|
| NC-101 | `cad/parts/NC-101_nose_tip.scad` | print | PETG | 19.62 | 24.9 | 0.0–160.0 | 28606 | True | None | `NC-101_nose_tip_section.stl` |
| NC-102 | `cad/parts/NC-102_nose_base.scad` | print | PETG | 50.50 | 64.1 | 150.0–324.0 | 39608 | True | None | `NC-102_nose_base_shoulder.stl` |
| NC-103 | `cad/parts/NC-103_nose_bulkhead.scad` | print | PETG | 16.76 | 12.8 | 318.0–324.0 | 1932 | True | None | `NC-103_nose_bulkhead_ballast_mount.stl` |
| PL-201 | `cad/parts/PL-201_payload_tube.scad` | tube | Kraft/phenolic tube | 50.05 | 50.0 | 264.0–514.0 | 3052 | True | None | drawing only |
| PL-202 | `cad/parts/PL-202_gps_tray.scad` | print | PETG | 14.86 | 18.9 | 348.0–438.0 | 5420 | True | None | `PL-202_gps_sensor_tray.stl` |
| PL-203 | `cad/parts/PL-203_camera_cradle.scad` | print | PETG | 10.24 | 11.7 | 336.9–385.0 | 564 | True | None | `PL-203_camera_cradle.stl` |
| PL-204 | `cad/parts/PL-204_lens_cowl.scad` | print | ASA | 2.70 | 1.7 | 342.8–386.0 | 1282 | True | None | `PL-204_lens_cowl.stl` |
| PL-205 | `cad/parts/PL-205_access_hatch.scad` | print | PETG | 0.76 | 1.0 | 375.3–414.7 | 1036 | True | None | `PL-205_access_hatch.stl` |
| PL-206 | `cad/parts/PL-206_hatch_frame.scad` | print | PETG | 1.19 | 1.5 | 368.0–422.0 | 2132 | True | None | `PL-206_hatch_doubler_frame.stl` |
| AV-301 | `cad/parts/AV-301_coupler.scad` | tube | Kraft/phenolic coupler | 46.54 | 46.5 | 444.0–614.0 | 3692 | True | None | drawing only |
| AV-302 | `cad/parts/AV-302_switch_band.scad` | tube | Body-tube offcut | 6.06 | 6.1 | 514.0–544.0 | 2788 | True | None | drawing only |
| AV-303 | `cad/parts/AV-303_fwd_bulkhead.scad` | ply | 6 mm birch ply x2 | 35.19 | 27.9 | 438.0–450.0 | 2704 | True | None | `AV-303-outer_forward_bulkhead_2_discs.dxf`<br>`AV-303-outer_forward_bulkhead_2_discs.svg`<br>`AV-303-inner_forward_bulkhead_2_discs.dxf`<br>`AV-303-inner_forward_bulkhead_2_discs.svg` |
| AV-304 | `cad/parts/AV-304_aft_bulkhead.scad` | ply | 6 mm birch ply x2 | 35.80 | 24.3 | 608.5–620.5 | 1928 | True | None | `AV-304-outer_aft_bulkhead_2_discs.dxf`<br>`AV-304-outer_aft_bulkhead_2_discs.svg`<br>`AV-304-inner_aft_bulkhead_2_discs.dxf`<br>`AV-304-inner_aft_bulkhead_2_discs.svg` |
| AV-306 | `cad/parts/AV-306_electronics_sled.scad` | print | PETG | 28.12 | 32.1 | 457.0–597.0 | 10872 | True | None | `AV-306_electronics_sled.stl` |
| AV-308 | `cad/parts/AV-308_battery_cage.scad` | print | PETG | 9.04 | 11.5 | 459.0–526.6 | 884 | True | None | `AV-308_battery_cage.stl` |
| AV-309 | `cad/parts/AV-309_gasket.scad` | foam | 1.5 mm EVA foam | 0.14 | 0.0 | 614.0–614.5 | 768 | True | None | `AV-309_aft_bulkhead_face_gasket.dxf`<br>`AV-309_aft_bulkhead_face_gasket.svg` |
| AV-312 | `cad/parts/AV-312_rod_spacers.scad` | print | PETG | 1.07 | 1.4 | 450.0–608.5 | 3072 | True | None | `AV-312-fwd_rod_spacers_2_fwd_2_aft.stl`<br>`AV-312-aft_rod_spacers_2_fwd_2_aft.stl` |
| BO-401 | `cad/parts/BO-401_booster_tube.scad` | tube | Kraft/phenolic tube | 120.56 | 120.6 | 544.0–1144.0 | 1672 | True | None | drawing only |
| BO-402 | `cad/parts/BO-402_motor_mount_tube.scad` | tube | 29 mm-class MMT | 24.49 | 24.5 | 894.0–1154.0 | 768 | True | None | drawing only |
| BO-403 | `cad/parts/BO-403_fincan_core.scad` | print | ASA | 73.12 | 66.5 | 996.0–1138.0 | 3700 | True | None | `BO-403_fin_can_core.stl` |
| BO-404 | `cad/parts/BO-404_fwd_centering_ring.scad` | ply | 6 mm birch ply | 14.38 | 9.8 | 894.0–900.0 | 764 | True | None | `BO-404_forward_centering_ring.dxf`<br>`BO-404_forward_centering_ring.svg` |
| BO-405 | `cad/parts/BO-405_fin_lock_ring.scad` | ply | 6 mm birch ply | 11.36 | 7.7 | 1138.0–1144.0 | 2320 | True | None | `BO-405_aft_fin_lock_ring.dxf`<br>`BO-405_aft_fin_lock_ring.svg` |
| BO-406 | `cad/parts/BO-406_fin.scad` | ply | 3 mm aircraft birch ply | 24.05 | 71.9 | 994.0–1144.0 | 28 | True | None | `BO-406_fin_x4_1_spare.dxf`<br>`BO-406_fin_x4_1_spare.svg` |
| BO-409 | `cad/parts/BO-409_rail_button_boss.scad` | print | PETG | 2.18 | 2.2 | 878.0–894.0 | 488 | True | None | `BO-409_forward_rail_button_boss.stl` |
| GS-701 | `cad/parts/GS-701_fin_jig.scad` | print | PETG | 51.42 | 19.6 | 1104.0–1134.0 | 784 | True | None | `GS-701_fin_alignment_jig_ground_support.stl` |

Commercial / purchased items are modelled as **envelopes** only (`COTS_envelopes.scad`):

| ID | Envelope | Volume cm³ | Z range mm |
|---|---|---|---|
| MT-601 | Certified motor envelope (EXTERNAL, placeholder length) | 79.13 | 1029.0–1154.0 |
| BO-407 | Commercial retainer envelope | 9.67 | 1144.0–1166.0 |
| BO-408 | Rail buttons (envelope) | 2.03 | 879.0–1121.0 |
| AV-311 | M6 forged eyebolt + nut (envelope) | 18.55 | 600.9–656.5 |
| AV-305 | M4 rods, tee-nuts, washers, nylock nuts | 5.67 | 436.5–628.0 |
| NC-104 | M6 ballast rod + nuts | 2.93 | 244.0–330.0 |
| AV-307 | Arming switch (USER envelope) | 1.15 | 523.0–535.0 |
| EL-MOD | MCU / IMU / baro / SD / radio envelopes | 16.64 | 468.0–596.0 |
| EL-BAT | Battery envelope | 13.86 | 465.3–520.3 |
| EL-GPS | GPS module envelope | 7.00 | 360.0–395.0 |
| EL-CAM | Camera envelope | 15.22 | 337.1–379.3 |

## 4. Validation results

### 4.1 Geometry validity (closed, consistently oriented 2-manifold; CGAL reports a simple polyhedron)

| Part | Closed | Open edges | Over-used edges | Degenerate tris | CGAL simple | Status |
|---|---|---|---|---|---|---|
| NC-101 | True | 0 | 0 | 0 | None | PASS |
| NC-102 | True | 0 | 0 | 32 | None | PASS |
| NC-103 | True | 0 | 0 | 0 | None | PASS |
| PL-201 | True | 0 | 0 | 0 | None | PASS |
| PL-202 | True | 0 | 0 | 0 | None | PASS |
| PL-203 | True | 0 | 0 | 0 | None | PASS |
| PL-204 | True | 0 | 0 | 0 | None | PASS |
| PL-205 | True | 0 | 0 | 0 | None | PASS |
| PL-206 | True | 0 | 0 | 0 | None | PASS |
| AV-301 | True | 0 | 0 | 0 | None | PASS |
| AV-302 | True | 0 | 0 | 0 | None | PASS |
| AV-303 | True | 0 | 0 | 0 | None | PASS |
| AV-304 | True | 0 | 0 | 0 | None | PASS |
| AV-306 | True | 0 | 0 | 0 | None | PASS |
| AV-308 | True | 0 | 0 | 0 | None | PASS |
| AV-309 | True | 0 | 0 | 0 | None | PASS |
| AV-312 | True | 0 | 0 | 0 | None | PASS |
| BO-401 | True | 0 | 0 | 0 | None | PASS |
| BO-402 | True | 0 | 0 | 0 | None | PASS |
| BO-403 | True | 0 | 0 | 0 | None | PASS |
| BO-404 | True | 0 | 0 | 0 | None | PASS |
| BO-405 | True | 0 | 0 | 0 | None | PASS |
| BO-406 | True | 0 | 0 | 0 | None | PASS |
| BO-409 | True | 0 | 0 | 0 | None | PASS |
| GS-701 | True | 0 | 0 | 0 | None | PASS |

### 4.2 Symmetry (centroid offset from the axis)

| Part | Expected | Offset mm | Status |
|---|---|---|---|
| NC-101 | axi | 0.0000 | PASS |
| NC-102 | axi3 | 0.0000 | PASS |
| NC-103 | axi3 | 0.0000 | PASS |
| AV-304 | axi2 | 0.0000 | PASS |
| AV-309 | axi | 0.0000 | PASS |
| BO-402 | axi | 0.0000 | PASS |
| BO-405 | axi4 | 0.0000 | PASS |
| GS-701 | axi4 | 0.0000 | PASS |
| BO-406 fin set | 4-fold | 0.0000 | PASS |

Parts not listed are deliberately asymmetric (features at a single angle).

### 4.3 Component interfaces

| ICD | Interface | CAD value | Requirement | Status |
|---|---|---|---|---|
| I-00 | Spigot / socket diametral clearance | 0.20 | +0.1/+0.3 | PASS |
| I-01 | NC-102 shoulder in PL-201 (diametral) | 0.300 | 0.15-0.45 (+0/-0.15 on 0.3) | PASS |
| I-02/03 | AV-301 in PL-201 / BO-401 (diametral) | 0.200 | 0.1-0.4 | PASS |
| I-02 | AV-303/304 inner disc in AV-301 (diametral) | 0.200 | >0 | PASS |
| I-04a | AV-304 on AV-309 gasket on coupler end face (axial stack) | 614.0 / 614.5 / 620.5 | contiguous | PASS |
| I-05 | Motor envelope in MMT (diametral) | 0.600 | per motor maker | PASS |
| I-06 | Fin in guide / slot / tab floor | 0.20 / 0.30 / 0.20 | 0.2 / 0.3 / 0.2 | PASS |
| I-06 | Lock ring covers tab ends (ring bore r vs tab root r) | 20.00 <= 20.20 | ring bore <= tab root | PASS |
| I-07 | Rail-button holes coaxial with hard points | see rail checks |  | PASS |
| I-08 | Harness hole vs tray foot (edge gap) | 4.0 | >= 2 | PASS |
| AV-305 | Rod in sleeve / AV-304 hole / tee-nut (diametral) | 0.4 / 0.5 / 1.5 | >0 | PASS |

### 4.4 Part interference

35 solids (flight parts, fin set, commercial envelopes) → 595 pairs. 485 pairs are separated by bounding box, 66 are proven clear by radial nesting, and **44 were intersected with CGAL**. Result: **0 interferences** (> 1.0 mm³), 25 coincident contacts (< 1.0 mm³), 19 clear.

| A | B | Overlap mm³ | Result |
|---|---|---|---|
| NC-101 | NC-102 | 0.000 | contact |
| NC-102 | NC-103 | 0.000 | contact |
| NC-102 | PL-201 | 0.000 | contact |
| NC-103 | NC-104 | 0.000 | contact |
| PL-201 | PL-204 | 0.005 | contact |
| PL-201 | PL-205 | 0.000 | contact |
| PL-201 | AV-302 | 0.000 | contact |
| PL-202 | AV-303 | 0.000 | contact |
| PL-203 | EL-CAM | 0.082 | contact |
| AV-301 | AV-303 | 0.000 | contact |
| AV-301 | AV-309 | 0.000 | contact |
| AV-302 | BO-401 | 0.000 | contact |
| AV-303 | AV-312 | 0.000 | contact |
| AV-303 | AV-305 | 0.000 | contact |
| AV-304 | AV-309 | 0.000 | contact |
| AV-304 | AV-312 | 0.000 | contact |
| AV-304 | AV-311 | 0.000 | contact |
| AV-304 | AV-305 | 0.000 | contact |
| AV-306 | AV-308 | 0.000 | contact |
| AV-306 | AV-312 | 0.000 | contact |
| BO-402 | BO-407 | 0.000 | contact |
| BO-403 | BO-405 | 0.000 | contact |
| BO-403 | BO-406-SET | 0.000 | contact |
| BO-404 | BO-409 | 0.000 | contact |
| BO-405 | BO-406-SET | 0.000 | contact |
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

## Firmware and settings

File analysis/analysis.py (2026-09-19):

"""
ASTRA-66 modular student rocket airframe -- parameter set and non-propulsion analysis.

Single source of truth: every number used by the drawings, the BOM, the OpenSCAD
parameter file and the HTML engineering package comes from this module.

Units: mm, g, N, s, m/s unless stated.

Provenance tags (required by the project brief):
  CALC  = CALCULATED VALUE          (derived here from other values)
  ASM   = ASSUMPTION                (engineering estimate -> must be verified / measured)
  USER  = USER-SUPPLIED VALUE       (you must provide it: measured part, range data ...)
  COTS  = COMMERCIAL COMPONENT SPECIFICATION (take from the manufacturer's current documents)

Nothing about propulsion is designed or optimised here. The motor is an EXTERNAL,
commercially certified component; the motor numbers below are PLACEHOLDERS that only
exist so the CG can be computed, and must be replaced with the selected motor's
published certification data.
"""
import json
import math
import os

CALC, ASM, USER, COTS = "CALC", "ASM", "USER", "COTS"
G0 = 9.81

P = {}
PROJECT_ROOT = os.path.dirname(os.path.dirname(os.path.abspath(__file__)))

# ----------------------------------------------------------------------------- external motor system data
# The certified motor and its commercial retainer are EXTERNAL components. Their data live in ONE file,
# simulation/motor_config.json. status = "PLACEHOLDER" (planning numbers, not a real product) or
# "MANUFACTURER_DATA" (values copied from the selected certified product's published documentation, with
# source, verifier and date recorded). Nothing here designs or modifies a motor.
MOTOR_CONFIG_FILE = os.path.join(PROJECT_ROOT, "simulation", "motor_config.json")


def _load_motor_config():
    with open(MOTOR_CONFIG_FILE, encoding="utf-8") as fh:
        cfg = json.load(fh)
    status = cfg.get("status")
    if status not in ("PLACEHOLDER", "MANUFACTURER_DATA"):
        raise ValueError("simulation/motor_config.json: status must be PLACEHOLDER or MANUFACTURER_DATA")
    numeric = [("motor", "length_mm"), ("motor", "loaded_mass_g"), ("motor", "burnout_mass_g"), ("retainer", "body_od_mm"),
               ("retainer", "length_aft_of_airframe_mm"), ("retainer", "mass_g"), ("motor_mount", "mmt_id_mm"),
               ("motor_mount", "mmt_length_mm"), ("motor_mount", "mmt_aft_extension_mm")]
    bad = [f"{a}.{b}" for a, b in numeric if not isinstance(cfg.get(a, {}).get(b), (int, float)) or cfg[a][b] <= 0]
    if bad:
        raise ValueError("simulation/motor_config.json: missing or non-positive " + ", ".join(bad))
    if status == "MANUFACTURER_DATA":
        req = [("motor", "designation"), ("motor", "manufacturer"), ("motor", "certification"), ("motor", "data_source"),
               ("retainer", "model"), ("retainer", "data_source"), ("verification", "verified_by"), ("verification", "date")]
        missing = [f"{a}.{b}" for a, b in req if not cfg.get(a, {}).get(b)]
        if missing:
            raise ValueError("simulation/motor_config.json: MANUFACTURER_DATA requires " + ", ".join(missing))
        if cfg["motor"]["burnout_mass_g"] >= cfg["motor"]["loaded_mass_g"]:
            raise ValueError("simulation/motor_config.json: burnout mass must be below loaded mass")
    return cfg


MOTOR_CFG = _load_motor_config()
MOTOR_STATUS = MOTOR_CFG["status"]


def _mnote(section, what):
    if MOTOR_STATUS == "PLACEHOLDER":
        return f"PLACEHOLDER ONLY ({what}). Replace via simulation/motor_config.json with the selected certified product's published data."
    v = MOTOR_CFG["verification"]
    return f"{what}: {MOTOR_CFG[section].get('data_source')} (motor_config.json, verified {v['date']} by {v['verified_by']})."


def p(name, value, unit, tag, note):
    P[name] = dict(name=name, v=value, u=unit, tag=tag, note=note)
    return value


# ----------------------------------------------------------------------------- airframe
BODY_OD = p("BODY_OD", 66.0, "mm", ASM, "Nominal 66 mm-class spiral kraft/phenolic body tube. MEASURE the purchased tube and update.")
BODY_ID = p("BODY_ID", 64.0, "mm", ASM, "Measure purchased tube (3 places, 2 axes). Drives every shoulder, ring and bulkhead fit.")
CPL_OD = p("CPL_OD", 63.8, "mm", ASM, "Matching commercial coupler. Must slip-fit BODY_ID (0.1-0.4 mm diametral clearance).")
CPL_ID = p("CPL_ID", 61.0, "mm", ASM, "Measure purchased coupler.")
TUBE_RHO = p("TUBE_RHO", 1.00, "g/cm3", ASM, "Effective density of paper/phenolic tube. Verify by weighing a known length.")
FIT_SH = p("FIT_SH", 0.30, "mm", ASM, "Diametral clearance, printed shoulder / ring in tube. Tune with a printed test coupon first.")

# ----------------------------------------------------------------------------- nose
NC_L = p("NC_L", 264.0, "mm", ASM, "Exposed nose length, tangent ogive, fineness 4.0 (NC_L / BODY_OD).")
NC_WALL = p("NC_WALL", 1.2, "mm", ASM, "Printed ogive wall = 3 perimeters x 0.4 mm nozzle.")
NC_SH_L = p("NC_SH_L", 60.0, "mm", ASM, "Shoulder length ~0.9 calibre.")
NC_SH_WALL = p("NC_SH_WALL", 1.6, "mm", ASM, "Shoulder wall (4 perimeters); hosts radial heat-set inserts.")
NC_SPLIT = p("NC_SPLIT", 150.0, "mm", ASM, "Print split station so each half fits a 250 mm Z-height printer.")
NC_BH_T = p("NC_BH_T", 6.0, "mm", ASM, "Printed nose bulkhead / ballast mount thickness.")
BALLAST_ROD_L = p("BALLAST_ROD_L", 80.0, "mm", ASM, "M6 A2 threaded rod length forward of NC-103 (rod is cut to BALLAST_ROD_L + NC_BH_T = 86).")
NC_TIP_SOLID = p("NC_TIP_SOLID", 8.0, "mm", ASM, "Solid printed tip before the internal cavity starts (CAD rev B).")
NC_SPIGOT_L = p("NC_SPIGOT_L", 10.0, "mm", ASM, "NC-101 spigot length aft of the print split (engages NC-102 socket).")
NC_SPLIT_WEB = p("NC_SPLIT_WEB", 2.0, "mm", ASM, "Solid annular web closing NC-101 at the split; the spigot grows from it (CAD rev B, printable).")
NC_SPIGOT_WALL = p("NC_SPIGOT_WALL", 1.6, "mm", ASM, "Spigot wall thickness.")
FIT_SOCKET = p("FIT_SOCKET", 0.2, "mm", ASM, "Diametral clearance spigot-to-socket (I-00, slip fit +0.1/+0.3).")
NC_BASE_RING = p("NC_BASE_RING", 1.6, "mm", ASM, "Closing ring between ogive wall and shoulder at the nose base.")
NC_BOSS_T = p("NC_BOSS_T", 4.4, "mm", ASM, "Radial insert boss depth inside the shoulder (wall + boss = 6.0 >= insert + 0.5).")
NC_LUG_L = p("NC_LUG_L", 12.0, "mm", ASM, "NC-103 mounting lug length (lugs end at the bulkhead forward face, CAD rev B).")
NC_LUG_T = p("NC_LUG_T", 6.0, "mm", ASM, "NC-103 mounting lug radial depth.")
NC_SCREW_ANG = p("NC_SCREW_ANG", [90, 210, 330], "deg", ASM, "Angular positions of the 3 radial nose screws (I-01).")
NC_LUG_ANG = p("NC_LUG_ANG", [30, 150, 270], "deg", ASM, "Angular positions of the 3 NC-103 lugs.")

# ----------------------------------------------------------------------------- payload
PL_L = p("PL_L", 250.0, "mm", ASM, "Payload tube length. Clear payload bay = PL_L - NC_SH_L - AV insertion - bulkheads.")
CAM_LENS_HOLE = p("CAM_LENS_HOLE", 14.0, "mm", USER, "Set from the chosen camera's lens barrel diameter + 1 mm.")
CAM_MASS = p("CAM_MASS", 35.0, "g", USER, "Weigh the chosen camera (with its cable). 35 g is a planning placeholder.")
CAM_OFF = p("CAM_OFF", 36.0, "mm", ASM, "Camera lens-hole station aft of the nose shoulder end (STA 360).")
CAM_ANG = p("CAM_ANG", 270, "deg", ASM, "Camera / lens-cowl angular position.")
CAM_TILT = p("CAM_TILT", 15.0, "deg", ASM, "Lens axis tilted aft from radial (matches the PL-204 window).")
CAM_W = p("CAM_W", 26.0, "mm", USER, "Camera body width (PLACEHOLDER: measure your camera). Rev B: 29 -> 26; the rev A 29 x 16 x 45 placeholder interfered with the tube wall at 15 deg tilt.")
CAM_H = p("CAM_H", 14.0, "mm", USER, "Camera body depth along the lens axis (PLACEHOLDER; rev A 16).")
CAM_LEN = p("CAM_LEN", 40.0, "mm", USER, "Camera body length (PLACEHOLDER; rev A 45). The CAD re-seats any size inside the bore; the pipeline then checks tray clearance.")
CAM_LENS_L = p("CAM_LENS_L", 5.0, "mm", USER, "Lens barrel protrusion from the camera face (PLACEHOLDER).")
HATCH_OFF = p("HATCH_OFF", 71.0, "mm", ASM, "Hatch centre station aft of the nose shoulder end (STA 395).")
HATCH_ANG = p("HATCH_ANG", 90, "deg", ASM, "Hatch angular position (over the GPS).")
HATCH_W = p("HATCH_W", 25.0, "mm", ASM, "Hatch cut-out chord width.")
HATCH_L = p("HATCH_L", 40.0, "mm", ASM, "Hatch cut-out axial length.")
HATCH_GAP = p("HATCH_GAP", 0.3, "mm", ASM, "Edge gap between hatch panel and cut-out.")
HATCH_SCREW_OFF = p("HATCH_SCREW_OFF", 17.0, "mm", ASM, "Hatch screws at hatch centre +/- this (on the frame ledges).")
FRAME_L = p("FRAME_L", 54.0, "mm", ASM, "PL-206 doubler frame axial length.")
FRAME_W = p("FRAME_W", 40.0, "mm", ASM, "PL-206 doubler frame chord width.")
FRAME_T = p("FRAME_T", 2.0, "mm", ASM, "PL-206 frame thickness (bosses 4.5).")
TRAY_L = p("TRAY_L", 90.0, "mm", ASM, "PL-202 overall length including the foot.")
TRAY_W = p("TRAY_W", 50.0, "mm", ASM, "PL-202 plate width.")
TRAY_T = p("TRAY_T", 2.5, "mm", ASM, "PL-202 plate thickness.")
TRAY_FOOT_T = p("TRAY_FOOT_T", 8.0, "mm", ASM, "PL-202 foot thickness (bears on AV-303).")
TRAY_HOLE_X = p("TRAY_HOLE_X", 7.0, "mm", ASM, "Tray screw holes at x = +/- this (CAD rev B: clears tee-nut flanges).")
TRAY_HOLE_Y = p("TRAY_HOLE_Y", -14.0, "mm", ASM, "Tray screw holes at y = this (below the sled plane).")

# ----------------------------------------------------------------------------- avionics bay
AV_CPL_L = p("AV_CPL_L", 170.0, "mm", ASM, "Coupler length = 70 insertion + 30 switch band + 70 insertion.")
AV_INS = p("AV_INS", 70.0, "mm", ASM, "Coupler insertion each side (~1.1 calibre; >= 1 calibre is the usual rule of thumb).")
AV_BAND_L = p("AV_BAND_L", 30.0, "mm", ASM, "Switch band length (exposed airframe ring).")
AV_BH_T = p("AV_BH_T", 6.0, "mm", ASM, "Each bulkhead disc thickness (birch ply); 2 discs per bulkhead.")
AV_ROD_SP = p("AV_ROD_SP", 40.0, "mm", ASM, "Threaded-rod spacing (M4) in the sled plane.")
SLED_L = p("SLED_L", 140.0, "mm", ASM, "Electronics sled length.")
SLED_W = p("SLED_W", 52.0, "mm", ASM, "Electronics sled width (fits CPL_ID with rod sleeves).")
SLED_T = p("SLED_T", 3.0, "mm", ASM, "Sled thickness (PETG, 100% infill between rod sleeves).")
SLED_FWD_GAP = p("SLED_FWD_GAP", 7.0, "mm", ASM, "Gap AV-303 to sled = forward AV-312 spacer length.")
GASKET_T = p("GASKET_T", 0.5, "mm", ASM, "AV-309 face gasket compressed thickness (1.5 mm foam free). CAD rev B: moves AV-304 outer disc aft by this.")
SW_ANG = p("SW_ANG", 90, "deg", ASM, "Arming-switch access angle.")
SW_HOLE_D = p("SW_HOLE_D", 8.0, "mm", ASM, "Switch access hole through AV-302 + AV-301.")
SW_TOWER_H = p("SW_TOWER_H", 20.0, "mm", USER, "Switch tower height above sled; set so the switch actuator sits ~1 mm below CPL_ID.")
STATIC_PORT_D = p("STATIC_PORT_D", 2.0, "mm", ASM, "4 static ports at 45/135/225/315 deg (size per sensor maker guidance).")
HARNESS_D = p("HARNESS_D", 8.0, "mm", ASM, "Harness hole through AV-303 (grommet).")
HARNESS_Y = p("HARNESS_Y", 14.0, "mm", ASM, "Harness hole centre offset toward the switch side (+Y).")
BAT_L = p("BAT_L", 55.0, "mm", USER, "Battery length (PLACEHOLDER: set from purchased cell).")
BAT_W = p("BAT_W", 28.0, "mm", USER, "Battery width (PLACEHOLDER; max 28.8 to clear the rod sleeves).")
BAT_H = p("BAT_H", 9.0, "mm", USER, "Battery thickness (PLACEHOLDER).")
ROD_L = p("ROD_L", 190.0, "mm", ASM, "AV-305 M4 rod length (fwd bulkhead face to 1.7 mm past the aft nut).")

# ----------------------------------------------------------------------------- booster
BO_L = p("BO_L", 600.0, "mm", ASM, "Booster tube length (recovery bay + fin can).")
MMT_OD = p("MMT_OD", 31.0, "mm", ASM, "29 mm-class motor mount tube OD. Measure purchased tube.")
MMT_ID = p("MMT_ID", float(MOTOR_CFG["motor_mount"]["mmt_id_mm"]), "mm", COTS, _mnote("motor_mount", "MMT bore for the motor casing"))
MMT_L = p("MMT_L", float(MOTOR_CFG["motor_mount"]["mmt_length_mm"]), "mm", COTS, _mnote("motor_mount", "MMT length >= longest motor + retainer requirement"))
MMT_AFT_EXT = p("MMT_AFT_EXT", float(MOTOR_CFG["motor_mount"]["mmt_aft_extension_mm"]), "mm", COTS, _mnote("motor_mount", "MMT protrusion aft of airframe for the retainer"))
CR_T = p("CR_T", 6.0, "mm", ASM, "Forward centering ring thickness (birch ply, recovery-load anchor ring).")
CORE_RING_T = p("CORE_RING_T", 8.0, "mm", ASM, "Fin-can core ring thickness (ASA print).")
CORE_RAIL_T = p("CORE_RAIL_T", 1.6, "mm", ASM, "Fin guide rail thickness.")
LOCK_T = p("LOCK_T", 6.0, "mm", ASM, "Aft fin lock ring thickness (birch ply: heat tolerant near motor).")
RET_CLEAR_D = p("RET_CLEAR_D", float(MOTOR_CFG["retainer"]["body_od_mm"]) + 1.0, "mm", COTS, "Lock-ring bore = retainer body OD + 1 mm. " + _mnote("retainer", "retainer body OD"))

FIN_N = p("FIN_N", 4, "-", ASM, "Fin count. 4 fins -> symmetric layout for rail buttons, camera and slide-in guides.")
FIN_CR = p("FIN_CR", 150.0, "mm", ASM, "Root chord (exposed).")
FIN_CT = p("FIN_CT", 60.0, "mm", ASM, "Tip chord.")
FIN_S = p("FIN_S", 60.0, "mm", ASM, "Semi-span (exposed, from body surface). Selected by trade study for 2-3 cal margin.")
FIN_XR = p("FIN_XR", 70.0, "mm", ASM, "Leading-edge sweep length (root LE to tip LE, parallel to axis). Tip TE stays 20 mm forward of the tail.")
FIN_T = p("FIN_T", 3.0, "mm", ASM, "Fin thickness: 3 mm aircraft birch ply (baseline) or 3.2 mm G10 (upgrade, heavier).")
FIN_TAB_FWD = p("FIN_TAB_FWD", 10.0, "mm", ASM, "Tab starts this far aft of root LE.")
FIN_SLOT_CLR = p("FIN_SLOT_CLR", 0.3, "mm", ASM, "Tube slot width = FIN_T + FIN_SLOT_CLR.")
FIN_GUIDE_CLR = p("FIN_GUIDE_CLR", 0.2, "mm", ASM, "Printed guide slot width = FIN_T + FIN_GUIDE_CLR.")
FIN_TAB_CLR = p("FIN_TAB_CLR", 0.2, "mm", ASM, "Radial clearance between fin tab root and the BO-403 tab floor.")
LOCK_SCREW_R = p("LOCK_SCREW_R", 26.0, "mm", ASM, "Pitch radius of the 4 lock-ring screws (45/135/225/315 deg).")
RB_FWD_OFF = p("RB_FWD_OFF", 9.0, "mm", ASM, "Forward rail button this far forward of the MMT forward end (on BO-409).")
RB_AFT_OFF = p("RB_AFT_OFF", 29.0, "mm", ASM, "Aft rail button this far forward of the tail (on BO-403 boss).")
RB_ANG = p("RB_ANG", 45, "deg", ASM, "Rail-button line, midway between fins 1 and 2.")
KEVLAR_NOTCH_ANG = p("KEVLAR_NOTCH_ANG", 225, "deg", ASM, "Aramid leader notch in BO-404 (opposite the rail line).")

# ----------------------------------------------------------------------------- hardware & CAD
INS_M3_D = p("INS_M3_D", 4.0, "mm", ASM, "Hole for M3 brass heat-set insert (use the insert maker's value).")
INS_M3_L = p("INS_M3_L", 5.0, "mm", ASM, "M3 insert length (insert maker).")
INS_M25_D = p("INS_M25_D", 3.6, "mm", ASM, "Hole for M2.5 heat-set insert (insert maker).")
INS_M25_L = p("INS_M25_L", 4.0, "mm", ASM, "M2.5 insert length (insert maker).")
INS_M4_D = p("INS_M4_D", 5.6, "mm", ASM, "Hole for M4 heat-set insert in printed bosses (insert maker).")
INS_M4_L = p("INS_M4_L", 6.0, "mm", ASM, "M4 insert length (insert maker).")
CLR_M25 = p("CLR_M25", 2.9, "mm", COTS, "ISO 273 medium clearance hole, M2.5.")
CLR_M3 = p("CLR_M3", 3.4, "mm", COTS, "ISO 273 medium clearance hole, M3.")
CLR_M4 = p("CLR_M4", 4.5, "mm", COTS, "ISO 273 medium clearance hole, M4.")
CLR_M6 = p("CLR_M6", 6.5, "mm", ASM, "Close clearance for the M6 eyebolt / ballast rod.")
TNUT_BARREL_D = p("TNUT_BARREL_D", 5.5, "mm", ASM, "M4 tee-nut barrel hole (confirm with purchased tee-nut).")
TNUT_FLANGE_D = p("TNUT_FLANGE_D", 15.0, "mm", ASM, "M4 tee-nut flange diameter (confirm; used for clearance checks).")
TNUT_FLANGE_T = p("TNUT_FLANGE_T", 1.5, "mm", ASM, "M4 tee-nut flange thickness (confirm).")
NUT_M4_H = p("NUT_M4_H", 5.0, "mm", COTS, "DIN 985 M4 nylock nut height (verify against purchased part).")
WASHER_M4_T = p("WASHER_M4_T", 0.8, "mm", COTS, "ISO 7089 M4 washer thickness.")
SHCS_M3_DK = p("SHCS_M3_DK", 5.5, "mm", COTS, "ISO 4762 M3 socket-head diameter (tool-access checks).")
RB_ENV_D = p("RB_ENV_D", 12.0, "mm", COTS, "Rail-button ENVELOPE placeholder diameter; real size from button maker.")
RB_ENV_H = p("RB_ENV_H", 9.0, "mm", COTS, "Rail-button ENVELOPE placeholder standoff; real size from button maker.")
EYE_ENV_D = p("EYE_ENV_D", 24.0, "mm", COTS, "M6 eyebolt ENVELOPE placeholder (eye OD); from eyebolt maker.")
EYE_ENV_L = p("EYE_ENV_L", 36.0, "mm", COTS, "M6 eyebolt ENVELOPE placeholder length aft of AV-304.")
RET_ENV_L = p("RET_ENV_L", float(MOTOR_CFG["retainer"]["length_aft_of_airframe_mm"]), "mm", COTS, _mnote("retainer", "retainer length aft of airframe"))
FN = p("FN", 96, "-", ASM, "OpenSCAD facets per full circle (CAD resolution only).")

PETG_RHO = p("PETG_RHO", 1.27, "g/cm3", ASM, "Typical PETG filament density (check spool datasheet).")
ASA_RHO = p("ASA_RHO", 1.07, "g/cm3", ASM, "Typical ASA filament density (check spool datasheet).")
PLY_RHO = p("PLY_RHO", 0.68, "g/cm3", ASM, "Aircraft birch plywood, typical. Weigh your sheet.")
STEEL_RHO = p("STEEL_RHO", 7.9, "g/cm3", ASM, "Stainless steel A2.")

# ----------------------------------------------------------------------------- motor (external)
MOTOR_L = p("MOTOR_L", float(MOTOR_CFG["motor"]["length_mm"]), "mm", COTS, _mnote("motor", "motor length"))
MOTOR_M0 = p("MOTOR_M0", float(MOTOR_CFG["motor"]["loaded_mass_g"]), "g", COTS, _mnote("motor", "loaded motor mass"))
MOTOR_MB = p("MOTOR_MB", float(MOTOR_CFG["motor"]["burnout_mass_g"]), "g", COTS, _mnote("motor", "burnout motor mass"))
RET_MASS = p("RET_MASS", float(MOTOR_CFG["retainer"]["mass_g"]), "g", COTS, _mnote("retainer", "retainer mass"))

# ----------------------------------------------------------------------------- recovery / environment
V_DESC = p("V_DESC", 5.0, "m/s", ASM, "Target descent rate under main parachute.")
CHUTE_D = p("CHUTE_D", 1067.0, "mm", ASM, "Selected nominal parachute diameter (42 in class) from the descent-rate calculation.")
CHUTE_CD = p("CHUTE_CD", 0.80, "-", ASM, "Parachute drag coefficient on nominal area. Replace with the chute manufacturer's figure if published.")
RHO_AIR = p("RHO_AIR", 1.225, "kg/m3", ASM, "ISA sea level. Use site altitude/temperature in the simulator (USER).")
SHOCK_K = p("SHOCK_K", 1.8, "-", ASM, "Opening-shock amplification over steady drag (conservative planning value).")
N_AX = p("N_AX", 15.0, "g", ASM, "Design axial load factor. REPLACE with 1.5 x simulated peak acceleration of the chosen motor.")
V_MAX = p("V_MAX", 90.0, "m/s", ASM, "Design velocity limit for this airframe (printed nose, kraft tubes, ply fins).")
ALPHA_GUST = p("ALPHA_GUST", 10.0, "deg", ASM, "Angle of attack for fin side-load check (rail exit in cross-wind).")
TAU_BOND = p("TAU_BOND", 1.0, "MPa", ASM, "Allowable shear on epoxy-to-paper tube bonds (paper delamination governs; very conservative).")
PLY_SIG = p("PLY_SIG", 40.0, "MPa", ASM, "Allowable bending stress, birch ply (conservative vs typical published values).")
PLY_G = p("PLY_G", 0.60, "GPa", ASM, "In-plane shear modulus, 3 mm birch ply (for flutter screening only).")
TUBE_E = p("TUBE_E", 3.0, "GPa", ASM, "Axial modulus of kraft/phenolic tube (vibration order-of-magnitude only).")
A2_70_PROOF = p("A2_70_PROOF", 450.0, "MPa", COTS, "ISO 3506-1 property class A2-70 minimum 0.2% proof stress.")
M4_AS = p("M4_AS", 8.78, "mm2", COTS, "ISO 898 / ISO 724 tensile stress area, M4 coarse.")
RAIL = p("RAIL", "1010", "-", USER, "Launch rail profile offered by YOUR range. Rail buttons must match it.")
RAIL_L = p("RAIL_L", 1.0, "m", USER, "Usable rail length at YOUR range (planning value 1.0 m).")

# ============================================================================ stations
X = {}
X["nc_base"] = NC_L
X["sh_end"] = NC_L + NC_SH_L
X["pl_end"] = NC_L + PL_L
X["band_end"] = X["pl_end"] + AV_BAND_L
X["end"] = X["band_end"] + BO_L
X["cpl_fwd"] = X["pl_end"] - AV_INS
X["cpl_aft"] = X["band_end"] + AV_INS
X["av_bh_fwd_outer"] = X["cpl_fwd"] - AV_BH_T
X["av_bh_aft_outer"] = X["cpl_aft"] + GASKET_T + AV_BH_T
X["sled_fwd"] = X["cpl_fwd"] + AV_BH_T + SLED_FWD_GAP
X["sled_aft"] = X["sled_fwd"] + SLED_L
X["mmt_fwd"] = X["end"] + MMT_AFT_EXT - MMT_L
X["mmt_aft"] = X["end"] + MMT_AFT_EXT
X["fin_le"] = X["end"] - FIN_CR
X["core_fwd"] = X["fin_le"] + FIN_TAB_FWD - CORE_RING_T
X["core_aft"] = X["end"] - LOCK_T
X["tab_fwd"] = X["fin_le"] + FIN_TAB_FWD
X["tab_aft"] = X["end"] - LOCK_T
X["motor_aft"] = X["mmt_aft"]
X["motor_fwd"] = X["motor_aft"] - MOTOR_L
X["rb_fwd"] = X["mmt_fwd"] - RB_FWD_OFF
X["rb_aft"] = X["end"] - RB_AFT_OFF
X["cam"] = X["sh_end"] + CAM_OFF
X["hatch"] = X["sh_end"] + HATCH_OFF
X["nc_screws"] = X["nc_base"] + NC_SH_L / 2
X["tray_fwd"] = X["av_bh_fwd_outer"] - TRAY_L
X["recovery_bay"] = (X["av_bh_aft_outer"], X["mmt_fwd"])

# Tab depth measured from the fin root line (tube OD). CAD rev B: the tab must clear the COTS retainer body
# (RET_CLEAR_D) so a fin can slide out aft with the retainer installed; the tab rests on BO-403 tab floors.
R_TAB_FLOOR = max(MMT_OD / 2, RET_CLEAR_D / 2)
FIN_TAB_H = BODY_OD / 2 - R_TAB_FLOOR - FIN_TAB_CLR
FIN_TAB_L = X["tab_aft"] - X["tab_fwd"]
PAYLOAD_BAY_CLEAR = X["av_bh_fwd_outer"] - X["sh_end"]
RECOVERY_BAY_L = X["mmt_fwd"] - X["av_bh_aft_outer"]


# ============================================================================ geometry helpers
def tube_g(od, idd, L, rho):
    return math.pi / 4 * (od ** 2 - idd ** 2) * L * rho / 1000.0


def disc_g(od, t, rho, idd=0.0):
    return tube_g(od, idd, t, rho)


def ogive_rho(R=BODY_OD / 2, L=NC_L):
    return (R * R + L * L) / (2 * R)


def ogive_r(x, R=BODY_OD / 2, L=NC_L):
    rho = ogive_rho(R, L)
    return math.sqrt(max(rho * rho - (L - x) ** 2, 0.0)) + R - rho
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

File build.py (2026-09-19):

"""Build the ASTRA-66 engineering package: python build.py

Sources:  analysis/analysis.py, simulation/motor_config.json, documentation/generator/*
Outputs:  cad/astra66_params.scad, analysis/results/*, bom/*.csv, simulation/openrocket_inputs.csv,
          avionics/electronics.csv + avionics/diagrams/*.svg, documentation/drawings/*.svg,
          documentation/ASTRA-66_Engineering_Package.html
"""
import csv
import html
import json
import os
import re
import sys

HERE = os.path.dirname(os.path.abspath(__file__))
sys.path.insert(0, os.path.join(HERE, "analysis"))
sys.path.insert(0, os.path.join(HERE, "documentation", "generator"))

import analysis as A  # noqa: E402
import data_tables as T  # noqa: E402
import drawings as D  # noqa: E402

DIAGRAMS = ("arch", "elec", "fsm")
TAGNAME = {"CALC": "CALCULATED", "ASM": "ASSUMPTION", "USER": "USER-SUPPLIED", "COTS": "COMMERCIAL SPEC"}


def esc(s):
    return html.escape(str(s))


def tag(t):
    key = t.split()[0].split("→")[0].split("(")[0].strip()
    cls = {"CALC": "calc", "ASM": "asm", "USER": "user", "COTS": "cots"}.get(key, "asm")
    label = TAGNAME.get(key, t)
    return f'<span class="tag t-{cls}">{esc(label)}</span>'


def tbl(headers, rows, cls="", num=(), raw=(), foot=None, caption=None):
    h = "".join(f'<th{" class=num" if i in num else ""}>{esc(x)}</th>' for i, x in enumerate(headers))
    body = []
    for r in rows:
        tds = []
        for i, c in enumerate(r):
            v = c if i in raw else esc(c)
            tds.append(f'<td{" class=num" if i in num else ""}>{v}</td>')
        body.append("<tr>" + "".join(tds) + "</tr>")
    ft = ""
    if foot:
        ft = "<tfoot><tr>" + "".join(f'<td{" class=num" if i in num else ""}>{c}</td>' for i, c in enumerate(foot)) + "</tr></tfoot>"
    cap = f"<caption>{esc(caption)}</caption>" if caption else ""
    return f'<div class="tw"><table class="{cls}">{cap}<thead><tr>{h}</tr></thead><tbody>{"".join(body)}</tbody>{ft}</table></div>'


def n(v, d=0):
    return f"{v:,.{d}f}"


def money(lo, hi):
    return f"${lo:,.0f}–{hi:,.0f}"


def main():
    R = A.run()
    X = A.X
    bw, ld, rec = R["bw"], R["loads"], R["recovery"]
    for d in ("cad", "analysis/results", "bom", "simulation", "avionics/diagrams", "documentation/drawings"):
        os.makedirs(os.path.join(HERE, d), exist_ok=True)

    # ------------------------------------------------------------------ OpenSCAD params
    lines = ["// ASTRA-66 parameters -- GENERATED by build.py from analysis.py. Edit analysis.py and rebuild,",
             "// or override here for quick CAD experiments (analysis will then be out of date).", ""]
    for p in A.P.values():
        if isinstance(p["v"], (int, float, list)):
            val = "[" + ", ".join(str(x) for x in p["v"]) + "]" if isinstance(p["v"], list) else p["v"]
            lines.append(f'{p["name"]:<16} = {val};   // [{TAGNAME[p["tag"]]}] {p["u"]} - {p["note"]}')
    params_path = os.path.join(HERE, "cad", "astra66_params.scad")
    new_params = "\n".join(lines) + "\n"
    old_params = open(params_path, encoding="utf-8").read() if os.path.exists(params_path) else None
    if new_params != old_params:          # keep the mtime when unchanged, so the CAD render cache stays valid
        open(params_path, "w", encoding="utf-8").write(new_params)

    # ------------------------------------------------------------------ CSV / JSON
    def wcsv(rel, header, rows):
        with open(os.path.join(HERE, *rel.split("/")), "w", newline="", encoding="utf-8") as fh:
            w = csv.writer(fh)
            w.writerow(header)
            w.writerows(rows)

    wcsv("analysis/results/parameters.csv", ["name", "value", "unit", "provenance", "note"],
         [[p["name"], p["v"], p["u"], TAGNAME[p["tag"]], p["note"]] for p in A.P.values()])
    wcsv("analysis/results/mass_budget.csv", ["id", "item", "module", "mass_g", "cg_station_mm", "provenance", "note"],
         [[i["id"], i["name"], i["module"], round(i["m"], 1), round(i["x"], 1), TAGNAME[i["tag"]], i["note"]] for i in R["items"]])
    wcsv("bom/bom.csv", ["part_no", "name", "module", "qty", "material", "method", "dimensions", "tolerance", "interface", "assembly",
                         "make_buy", "cost_usd_low", "cost_usd_high", "in_low_cost_build", "purpose"],
         [[p["pn"], p["name"], p["mod"], p["qty"], p["mat"], p["meth"], p["dims"], p["tol"], p["iface"], p["assy"], p["make"],
           p["lo"], p["hi"], p["ver"] == "both", p["purpose"]] for p in T.PARTS])
    wcsv("bom/fasteners.csv", ["fastener", "qty", "standard", "used_at"], [list(r) for r in T.FASTENERS])
    wcsv("bom/materials.csv", ["material", "quantity", "parts", "note", "cost_usd_low", "cost_usd_high"], [list(r) for r in T.MATERIALS])
    wcsv("avionics/electronics.csv", ["function", "example_class", "role", "bus", "location", "cost_usd_low", "cost_usd_high", "build"],
         [[e["mod"], e["ex"], e["fn"], e["bus"], e["loc"], e["lo"], e["hi"], e["ver"]] for e in T.ELECTRONICS])
    wcsv("simulation/openrocket_inputs.csv", ["component", "field", "value", "provenance"], [list(r) for r in T.OPENROCKET])
    summary = {k: R[k] for k in ("M0", "Mb", "Me", "cg0", "cgb", "cge", "sm0", "smb", "sme", "L", "LD")}
    summary.update(cp=bw["xcp"], loads=ld, recovery=rec, nose=R["nose"], trade=R["trade"], stations=X, motor_status=A.MOTOR_STATUS)
    json.dump(summary, open(os.path.join(HERE, "analysis", "results", "analysis.json"), "w"), indent=2, default=str)

    # ------------------------------------------------------------------ drawings
    sheets = D.all_sheets(R)
    S = {}
    for k, sh in sheets.items():
        svg = sh.render()
        S[k] = svg
        dest = ("avionics", "diagrams") if k in DIAGRAMS else ("documentation", "drawings")
        open(os.path.join(HERE, *dest, f"{k}.svg"), "w", encoding="utf-8").write(D.standalone(svg))
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

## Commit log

2026-09-19 feat: initial ASTRA-66 engineering package
    [AV-301_coupler.scad, AV-302_switch_band.scad, AV-303-inner_forward_bulkhead_2_discs.dxf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]
2026-09-20 feat: add ASTRA-66 avionics and flight-data framework
    Phases 4-6: sensing, data logging, telemetry, ground station and post-flight
    analysis, with hardware-agnostic verification and integration checks.
    - firmware: hardware-independent sensor interface, Kalman vertical-state
    estimator, flight-state classifier (data labels only), schema-validated
    logger with CRC-16 rows, telemetry packet v2 with sensor-health bits
    - data: flight-data schema v1.1.0, SYNTHETIC / BENCH / FLIGHT data-source
    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
    [avionics_mass_properties.csv, example_bench_record.csv, example_flight_simulated.csv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]
2026-09-20 docs: finalize ASTRA-66 release package
    Portfolio documentation set and release freeze record. No engineering change:
    CAD geometry, analysis, simulation results, avionics algorithms, hardware
    assumptions and placeholder propulsion data are untouched.
    - documentation: project overview, engineering method, validation, hardware
    integration, test plan, reproducibility, roadmap, release readiness
    - README rewritten as an engineering portfolio page with real badges, existing
    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
2026-09-21 feat: deploy ASTRA-66 3D flight visualization
    Turns the local 3D simulator into a deployable static website.
    - website shell around the existing simulator: hero, 3D stage, flight data,
    engineering system, validation, limitations, about and footer sections, all
    rendered from the same exported JSON as the 3D view
    - vercel.json at the repository root so importing the repo needs no settings
    (install/build in visualization/, output visualization/dist)
    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
2026-09-21 fix: nav wrapping on narrow screens and flaky browser tests
    - keep the ASTRA-66 wordmark on one line below 380 px and tighten the nav
    - poll for playback and for the off-screen flag in the browser tests instead
    of fixed sleeps (one run flaked on a fixed 450 ms wait)
    - kill the headless Chrome process tree and remove its profile after each
    suite: leftover renderer processes accumulated on Windows and slowed
    repeated runs from ~18 s to over 200 s
    - capture blank-frame checks at quarter scale, since the PNG decoder used to
    analyse them is pure Python
2026-09-21 fix: usable mobile layout for the simulator
    On a phone the engineering panels and the floating control groups covered the
    whole 3D view.
    - panels become an overlay drawer that is closed by default below 1150 px and
    opens with the PANELS button (CSS-driven, so it also survives a resize or a
    rotation, which the previous startup-only check did not)
    - telemetry becomes a compact full-width strip; view controls become a
    horizontally scrollable rail along the bottom of the canvas
    - taller stage and tighter transport on small screens
    - test: on a 390 px viewport the drawer must be closed and the PANELS button
    must open it
2026-10-20 test(visualization): trace telemetry through playback sources
